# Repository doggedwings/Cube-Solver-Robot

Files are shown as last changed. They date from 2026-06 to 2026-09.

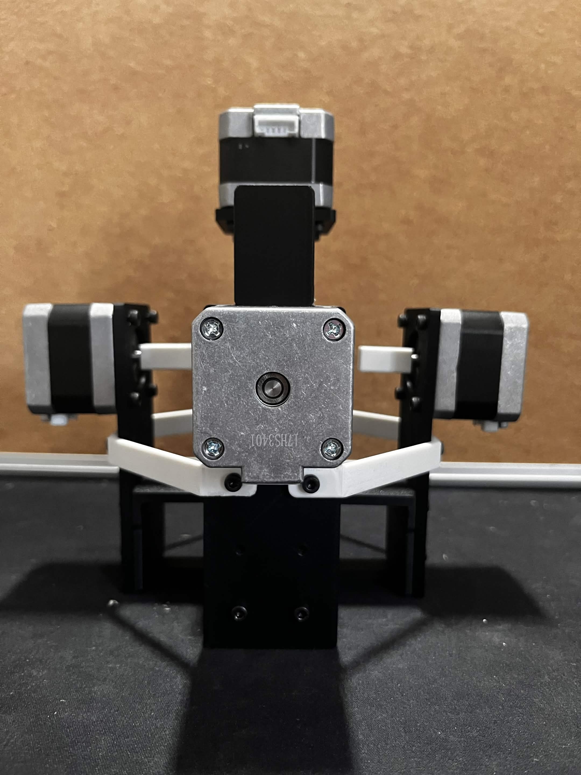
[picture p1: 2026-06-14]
Media/Side View.jpg

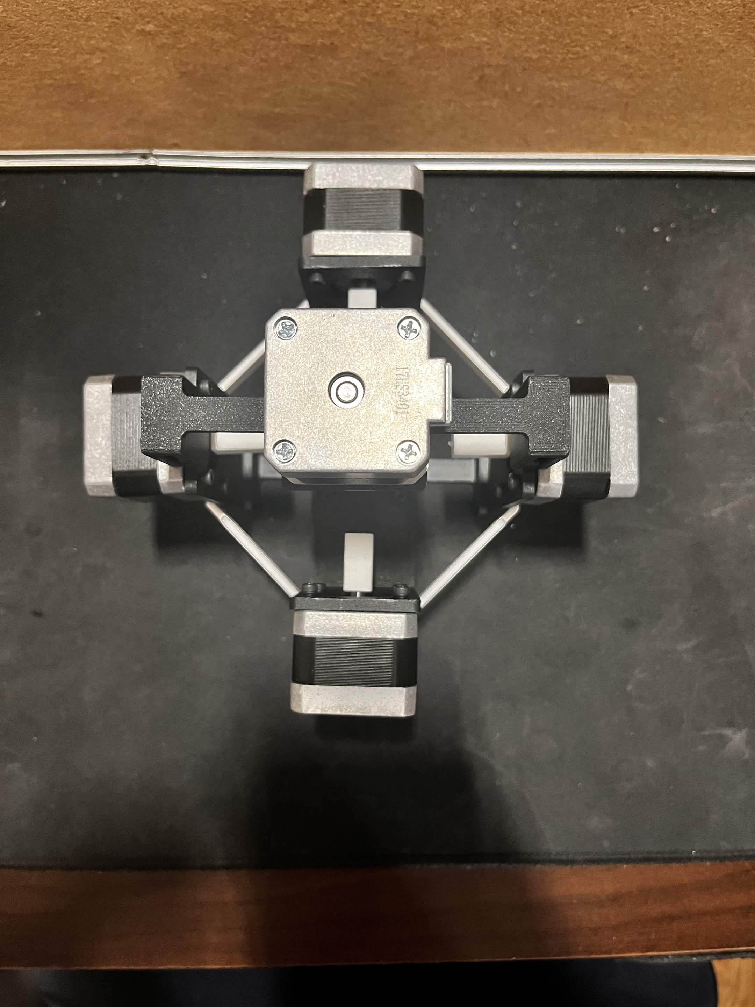
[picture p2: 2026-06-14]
Media/Top View.jpg

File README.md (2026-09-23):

# Rubik's Cube Solver Robot

An autonomous Rubik's Cube solving robot built around an ESP32, six NEMA 17 stepper motors, a custom 3D printed frame, and a web app that scans the cube using a phone camera and solves it with the Kociemba algorithm, which can solve a scrambled 3x3 cube in under 10 seconds. 



## WATCH THE SOLVE HERE 
https://youtube.com/shorts/RGmkUIyBiMk?feature=share

## Why I Built This
I've been solving Rubik's Cubes casually for almost a decade, and my best time is still over 20 seconds. I figured if I couldn't get faster, I'd build something that could. This robot scans a scrambled cube with a phone camera, computes the optimal solution, and physically solves it in well under 10 seconds using 6 stepper motors.

## How It Works

You scramble a cube and place it in the frame. Open the web app on your phone, calibrate the 6 colours, and scan all 6 faces by holding the cube up to the camera one face at a time. The app figures out the cube state, runs it through a solving algorithm, and sends the move sequence to the robot, which then physically executes every turn until the cube is solved.

## Hardware Specs

The Brain: ESP32-WROOM-32D, drives all 6 stepper motors over Serial commands
The Motors: 6x NEMA 17, one per cube face
The Drivers: 6x A4988 stepper drivers, full-step mode, ~50 steps per 90° turn
Power: 12V wall adapter for motors, USB for ESP32 logic
The Eyes: Phone camera or webcam for scanning cube faces
The Solver: Kociemba two-phase algorithm (Python), returns optimal solution in under a second
Frame & Couplers: Custom 3D printed (PETG), Fusion 360 designed

## Engineering 

1. Color Detection That Actually Works

Red and orange kept getting confused with fixed HSV thresholds. The fix was calibrating against the specific cube and lighting: white is detected by saturation (cutoff set between calibrated white and the least saturated colour), and every other sticker is classified by circular hue distance to the calibrated reference hues. This correctly handles red wrapping around 0/180 in HSV, which finally separated red from orange reliably. 

2. 6 Motor Coordination Over Serial

The ESP32 receives a full move sequence (e.g. R U2 D' B D' L2 F') as one string over Serial, parses it move by move, and executes each one including double turns and inverses by reversing direction or doubling the step count. Each motor also has its own tunable step count since print tolerances varied slightly across the 6 couplers. 

3. The Coupler Design (4 Iterations Deep)

Connecting a 5mm D shaft motor to a Rubik's cube center cap was harder than expected. The final design is a hex peg that seats into the center cap hole, with a D bore and set screw on the motor side. It took 4 print iterations since PETG shrinks about 0.1 to 0.2mm from the CAD dimensions, so each version had to compensate to get a snug fit. 

4. Phone Camera Over HTTPS

Browsers block camera access on non-HTTPS connections, so the Flask app runs with an ad hoc SSL context, letting the phone connect over the local network and stream camera frames to the server for processing. 

## Schematic 

*Note that the A4988 Motor Driver used in the schematic is different from the one used in the actual build, but the logic is the same, just the pinouts are different
Schematic

## CAD 

Custom design 3d printed frame made in Fusion 360, 6 motor mounts (4 side + top + bottom), magnetic top piece for easy clip on and off for cube loading, and stepper motor connector that goes into the stepper motor shaft and connects to a hex design cube connector that turns the face. 



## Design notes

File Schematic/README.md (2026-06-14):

## Note on A4988 Component

The A4988 symbol used in the KiCad schematic is not the exact same footprint as the physical Pololu A4988 breakout board used in the actual build. The correct breakout board footprint was not available in the KiCad library at the time. The pin functions and connections are identical, only the pin numbering differs between the schematic symbol and the physical board, so the wiring logic is fully accurate.

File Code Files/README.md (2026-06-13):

## Tutorial on how to run it

ESP32:

Open Motor_controller.ino in Arduino IDE
Board: ESP32 Dev Module, select the correct COM port, and upload

Web App:

IN TERMINAL OR BASH
pip install flask opencv-python numpy pyserial kociemba
python code/python/app.py

Open the printed HTTPS address on your phone, allow camera access, calibrate, scan, solve.

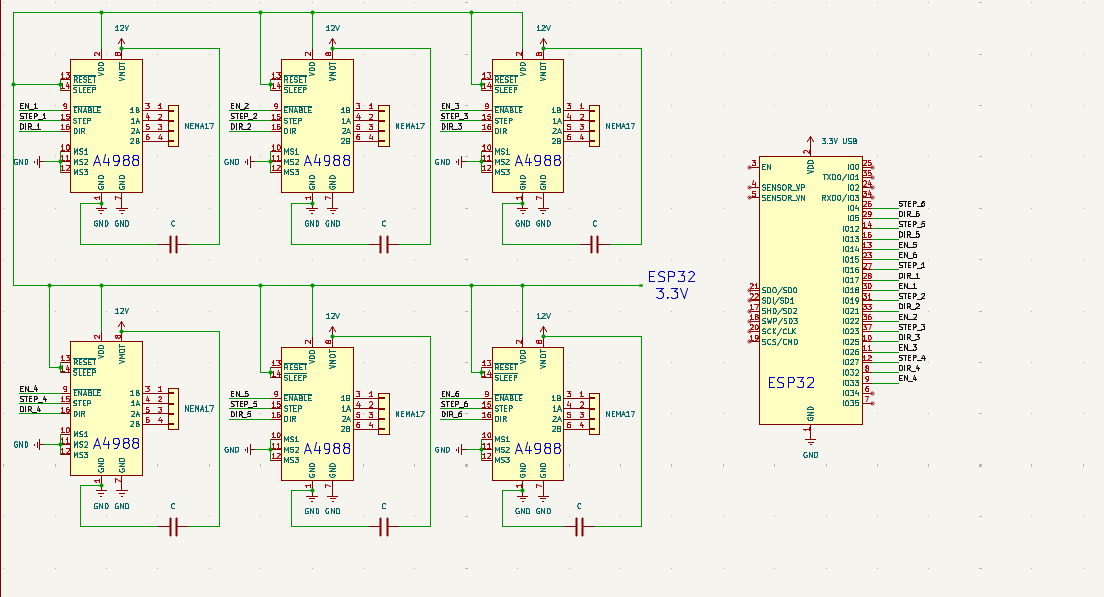
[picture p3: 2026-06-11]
Schematic/Schematic.png

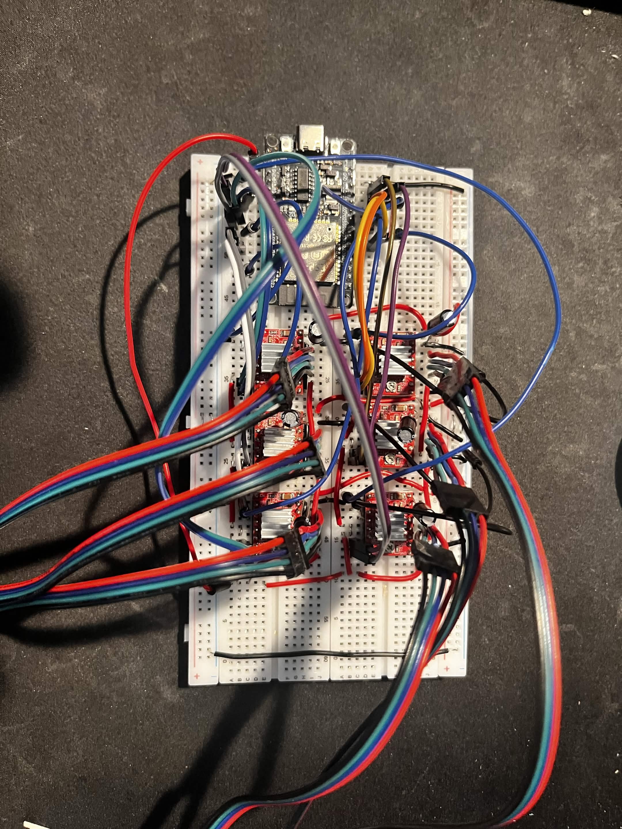
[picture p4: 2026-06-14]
Media/Built Breadboard Circuit.jpg

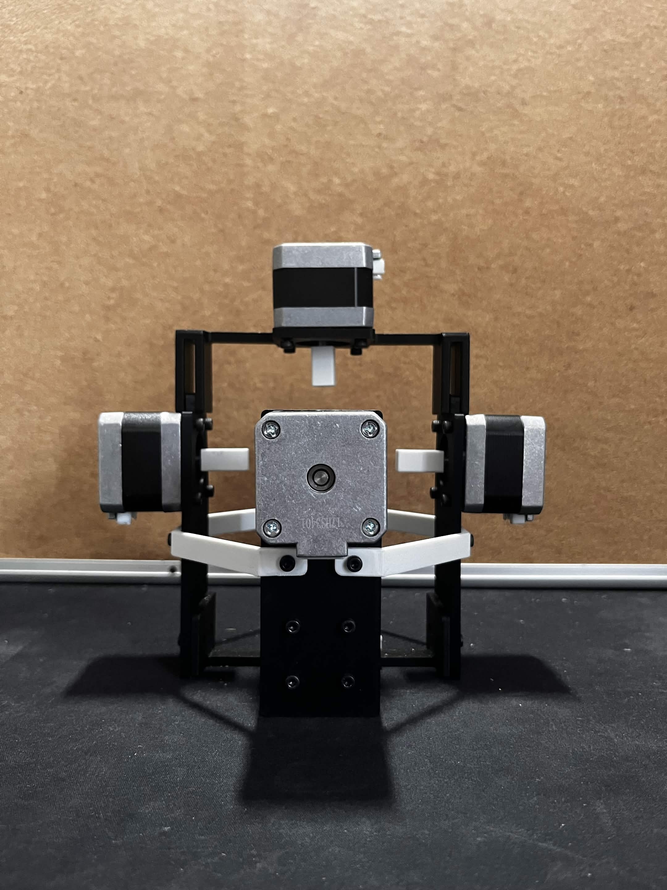
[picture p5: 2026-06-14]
Media/Front View.jpg

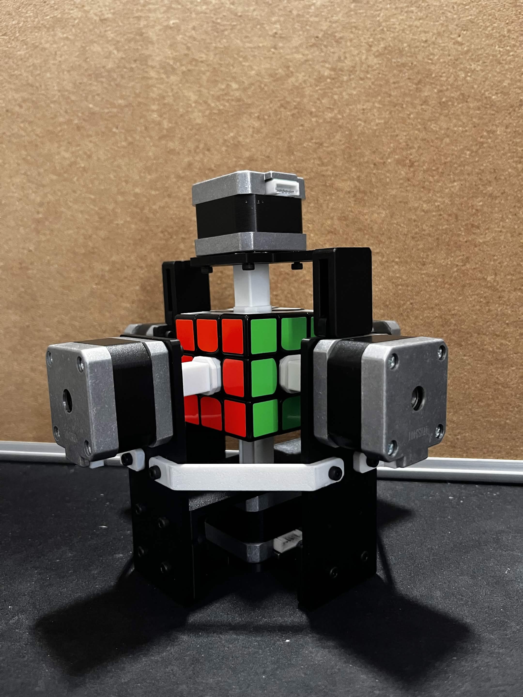
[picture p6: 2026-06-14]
Media/Full View.jpg

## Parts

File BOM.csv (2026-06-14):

Item | Amount | Source | Cost | Total Cost
ESP-32 | 1 | AliExpress | $4.50 | $4.50
A4988 | 6 | Amazon | $2.20 | $13.20
NEMA17 Pancake Stepper Motor | 6 | Amazon | $9.50 | $57.00
Rubicks Cube (GAN356, Moyu Weilong) | 1 | Already Have | $0.00 | $0.00

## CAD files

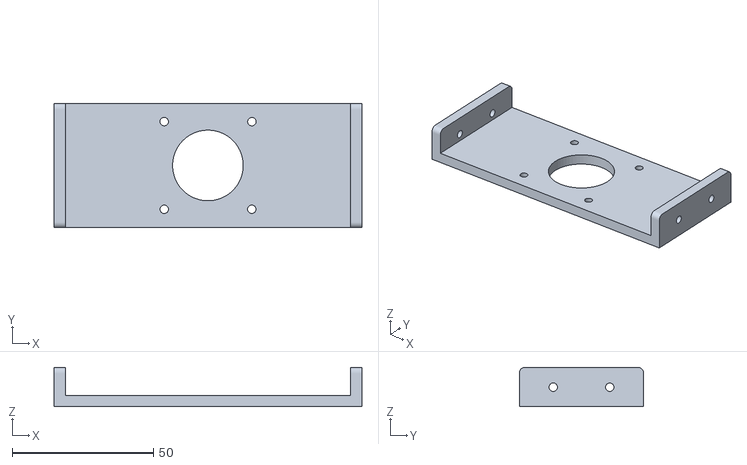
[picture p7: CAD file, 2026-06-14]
CAD Files/Base Plate.stl
109.0 x 44.0 x 14.0

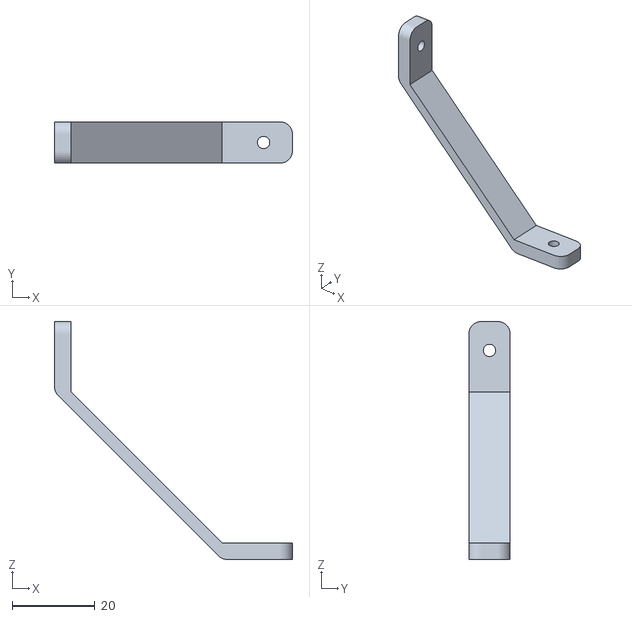
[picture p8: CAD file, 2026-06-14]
CAD Files/Side Plate Support Connector.stl
57.5 x 10.0 x 57.5

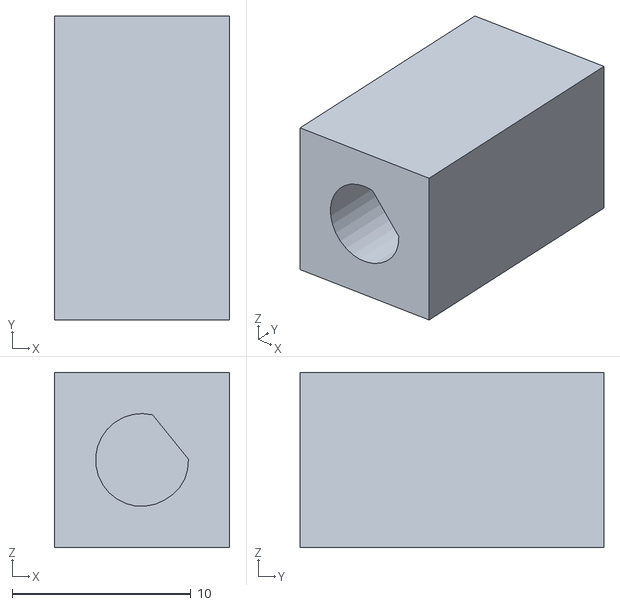
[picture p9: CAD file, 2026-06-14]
CAD Files/Stepper Motor Connector.stl
9.80 x 17.0 x 9.80

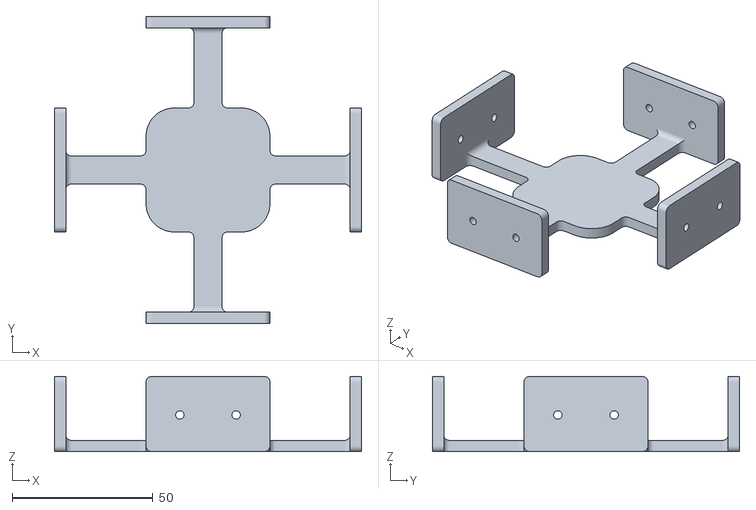
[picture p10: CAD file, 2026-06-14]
CAD Files/Base Web.stl
109.0 x 109.0 x 26.7

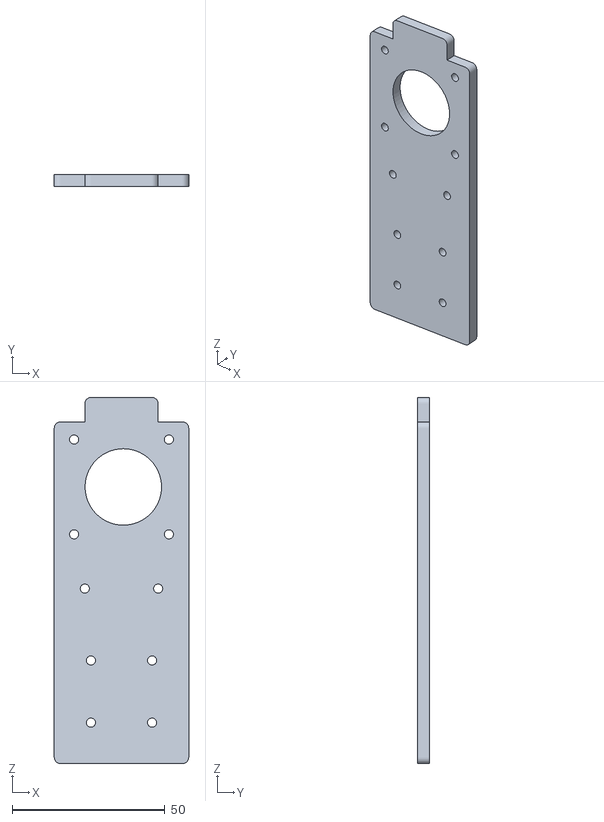
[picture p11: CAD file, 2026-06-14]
CAD Files/SIde Plate with Top Connector.stl
44.0 x 4.00 x 119.7

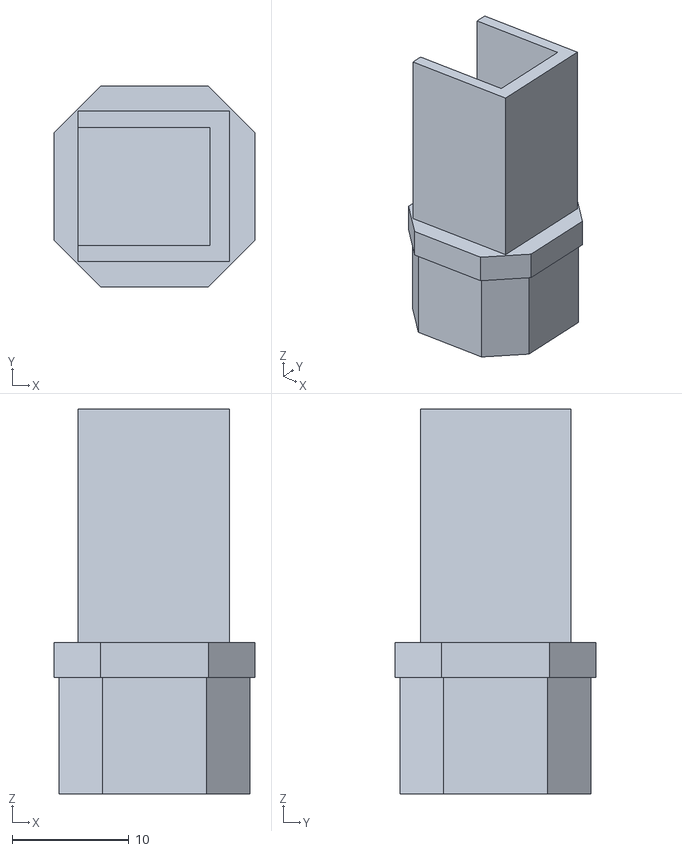
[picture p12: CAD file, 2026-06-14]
CAD Files/Cube Connector.stl
17.2 x 17.2 x 33.0

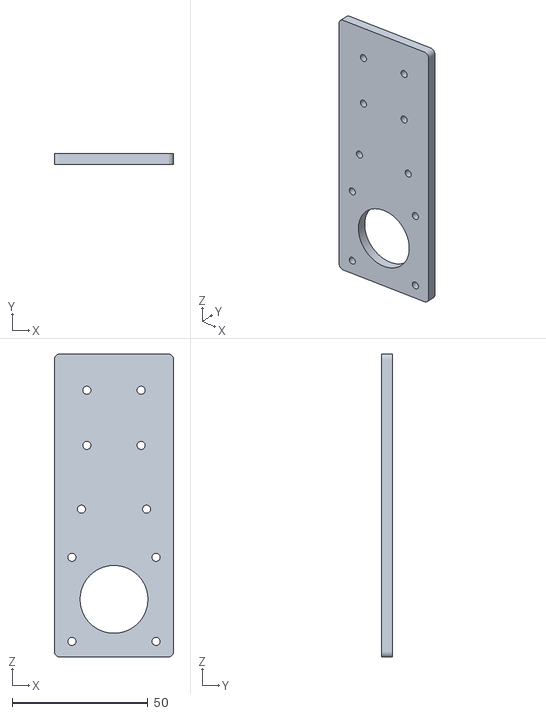
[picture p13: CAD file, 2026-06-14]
CAD Files/Side Plate no Top Connector.stl
44.0 x 4.00 x 111.7

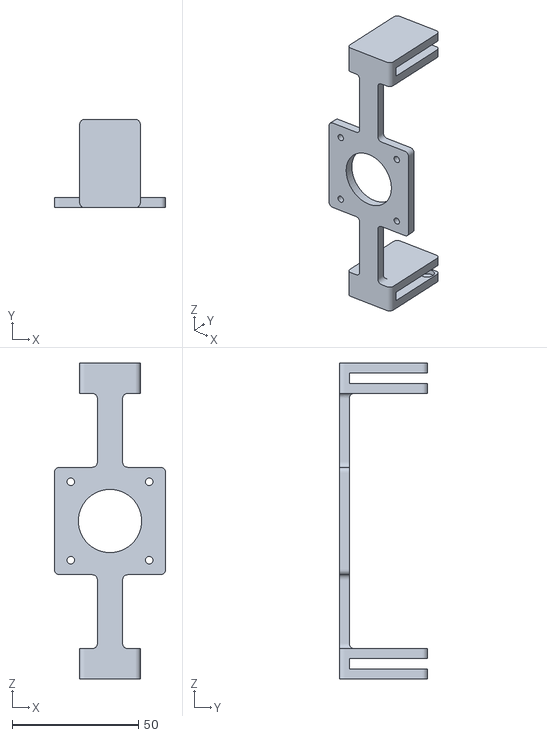
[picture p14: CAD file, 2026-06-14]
CAD Files/Top Connector.stl
44.0 x 35.0 x 125.0

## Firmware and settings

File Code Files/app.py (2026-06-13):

import cv2
import numpy as np
import kociemba
import threading
import time
import base64
import serial
import serial.tools.list_ports
from flask import Flask, Response, jsonify, render_template_string, request

app = Flask(__name__)

FACE_LABELS = {
    "U": "White / Up",
    "R": "Red / Right",
    "F": "Green / Front",
    "D": "Yellow / Down",
    "L": "Orange / Left",
    "B": "Blue / Back",
}

FACE_CSS = {
    "U": "#ffffff",
    "R": "#c41e3a",
    "F": "#009b48",
    "D": "#ffd500",
    "L": "#ff5800",
    "B": "#0046ad",
}

SERIAL_PORT = "COM3"
SERIAL_BAUD = 115200
serial_conn = None

def connect_serial():
    global serial_conn
    try:
        serial_conn = serial.Serial(SERIAL_PORT, SERIAL_BAUD, timeout=2)
        time.sleep(2)
        print(f"Serial connected on {SERIAL_PORT}")
    except Exception as e:
        print(f"Serial not connected: {e}")
        serial_conn = None

def send_solution_serial(solution_str):
    if serial_conn and serial_conn.is_open:
        serial_conn.write((solution_str + '\n').encode())
        print(f"Sent to ESP32: {solution_str}")
        return True
    print("Serial not connected")
    return False

state = {
    "refs": {},
    "faces": {f: None for f in "URFDLB"},
    "calibrating": True,
    "calib_face": "U",
    "solution": None,
    "error": None,
    "last_frame": None,  # base64 jpeg from phone
}
state_lock = threading.Lock()

# ── Colour helpers ────────────────────────────────────────────
def hue_dist(h1, h2):
    d = abs(int(h1) - int(h2))
    return min(d, 180 - d)

def color_dist(hsv1, ref):
    h1, s1, v1 = hsv1
    h2, s2, v2 = ref
    dh = hue_dist(h1, h2) * 2
    return dh * dh + (int(s1) - int(s2)) ** 2 + (int(v1) - int(v2)) ** 2

def build_thresholds(refs):
    """Adaptive thresholds anchored by the 6 calibration samples."""
    white_s = refs["U"][1]
    colored_sats = [refs[f][1] for f in "RFDLB"]
    min_colored_s = min(colored_sats)
    return {
        "white_s_max": (white_s + min_colored_s) / 2.0,
        "hues": {
            "R": refs["R"][0],
            "L": refs["L"][0],
            "D": refs["D"][0],
            "F": refs["F"][0],
            "B": refs["B"][0],
        },
    }

def classify_color(hsv, refs):
    """Calibrated hue-distance classifier.

    1. White detected by LOW SATURATION — cutoff sits halfway between the
       calibrated white saturation and the least-saturated colored face,
       so it adapts to your lighting instead of using a fixed number.
    2. All other stickers classified by NEAREST CALIBRATED HUE using
       circular hue distance — correctly handles red wrapping around
       0/180 in OpenCV HSV space, and separates red from orange based on
       the actual calibrated hues of YOUR cube under YOUR lighting.
    Value (brightness) is deliberately ignored for colors — brightness
    varies with shadows/angle but hue stays stable, which is what makes
    this approach accurate.
    """
    if len(refs) < 6:
        return "?"
    h, s, v = hsv
    t = build_thresholds(refs)
    if s <= t["white_s_max"] and v > 90:
        return "U"
    best, best_d = "U", 999
    for face, ref_h in t["hues"].items():
        d = hue_dist(h, ref_h)
        if d < best_d:
            best_d, best = d, face
    return best

def decode_frame(b64_data):
    """Decode base64 image from phone camera."""
    try:
        if ',' in b64_data:
            b64_data = b64_data.split(',')[1]
        img_bytes = base64.b64decode(b64_data)
        np_arr = np.frombuffer(img_bytes, np.uint8)
        frame = cv2.imdecode(np_arr, cv2.IMREAD_COLOR)
        return frame
    except Exception as e:
        print(f"Frame decode error: {e}")
        return None

def draw_calib_overlay(frame, face):
    fh, fw = frame.shape[:2]
    # Calibration box matches the size of ONE cell of the 3x3 scan grid
    side = int(min(fh, fw) * 0.85)
    grid_size = side // 3 - 6
    sz = grid_size // 2
    cx, cy = fw // 2, fh // 2
    x1, y1, x2, y2 = cx - sz, cy - sz, cx + sz, cy + sz
    cv2.rectangle(frame, (x1, y1), (x2, y2), (0, 255, 255), 3)
    cv2.putText(frame, f"Calibrate: {FACE_LABELS[face]}",
                (10, 30), cv2.FONT_HERSHEY_SIMPLEX, 0.65, (0, 255, 255), 2)
    hsv_f = cv2.cvtColor(frame, cv2.COLOR_BGR2HSV)
    roi = hsv_f[y1:y2, x1:x2]
    pad = max(1, sz // 2)
    if roi.shape[0] > 2 * pad and roi.shape[1] > 2 * pad:
        inner = roi[pad:-pad, pad:-pad]
    else:
        inner = roi
    ah = int(np.median(inner[:, :, 0]))
    as_ = int(np.median(inner[:, :, 1]))
    av = int(np.median(inner[:, :, 2]))
    cv2.putText(frame, f"HSV: {ah},{as_},{av}", (x1, y2 + 20),
                cv2.FONT_HERSHEY_SIMPLEX, 0.48, (255, 255, 0), 1)
    return (ah, as_, av)

def sample_face(frame, refs):
    h, w = frame.shape[:2]
    side = int(min(h, w) * 0.85)
    grid_size = side // 3 - 6
    spacing = 6
    total = 3 * grid_size + 2 * spacing
    sx = w // 2 - total // 2
    sy = h // 2 - total // 2
    hsv_frame = cv2.cvtColor(frame, cv2.COLOR_BGR2HSV)
    labels = []
    for row in range(3):
        for col in range(3):
            x = sx + col * (grid_size + spacing)
            y = sy + row * (grid_size + spacing)
            cv2.rectangle(frame, (x, y), (x + grid_size, y + grid_size), (0, 255, 0), 2)
            roi = hsv_frame[y:y + grid_size, x:x + grid_size]
            pad = grid_size // 4
            inner = roi[pad:-pad, pad:-pad]
            avg = (int(np.median(inner[:, :, 0])),
                   int(np.median(inner[:, :, 1])),
                   int(np.median(inner[:, :, 2])))
            label = classify_color(avg, refs) if refs else "?"
            labels.append(label)
            cv2.putText(frame, label, (x + 5, y + 22),
                        cv2.FONT_HERSHEY_SIMPLEX, 0.6, (0, 255, 0), 2)
    return labels

# ── Routes ────────────────────────────────────────────────────
@app.route("/")
def index():
    return render_template_string(HTML)

@app.route("/api/frame", methods=["POST"])
def api_frame():
    """Receive frame from phone camera via POST."""
    data = request.get_json()
    if not data or 'frame' not in data:
        return jsonify(error="No frame"), 400
    frame = decode_frame(data['frame'])
    if frame is None:
        return jsonify(error="Bad frame"), 400

    with state_lock:
        calibrating = state["calibrating"]
        calib_face = state["calib_face"]
        refs = dict(state["refs"])

    hsv_reading = None
    labels = None

    if calibrating and calib_face:
        hsv_reading = draw_calib_overlay(frame, calib_face)
        with state_lock:
            state["current_hsv"] = hsv_reading
    elif refs:
        labels = sample_face(frame, refs)

    ret, jpeg = cv2.imencode(".jpg", frame, [cv2.IMWRITE_JPEG_QUALITY, 72])
    if ret:
        b64 = base64.b64encode(jpeg.tobytes()).decode()
        with state_lock:
            state["last_frame"] = b64

    return jsonify(ok=True, hsv=hsv_reading, labels=labels)

@app.route("/api/state")
def api_state():
    with state_lock:
        refs_keys = list(state["refs"].keys())
        faces = {k: v for k, v in state["faces"].items()}
        calibrating = state["calibrating"]
        calib_face = state["calib_face"]
        solution = state["solution"]
        error = state["error"]
        last_frame = state.get("last_frame")
    serial_status = "connected" if serial_conn and serial_conn.is_open else "disconnected"
    return jsonify(refs=refs_keys, faces=faces, calibrating=calibrating,
                   calib_face=calib_face, solution=solution, error=error,
                   serial=serial_status, last_frame=last_frame)

@app.route("/api/calibrate/<face>", methods=["POST"])
def api_calibrate(face):
    face = face.upper()
    if face not in "URFDLB":
        return jsonify(error="Invalid face"), 400
    with state_lock:
        hsv = state.get("current_hsv")
        if hsv is None:
            return jsonify(error="No frame yet — point camera at cube first"), 500
        state["refs"][face] = hsv
        order = list("URFDLB")
        idx = order.index(face)
        if idx + 1 < len(order):
            state["calib_face"] = order[idx + 1]
            state["calibrating"] = True
        else:
            state["calibrating"] = False
            state["calib_face"] = None
    return jsonify(ok=True, face=face, hsv=hsv)

@app.route("/api/capture/<face>", methods=["POST"])
def api_capture(face):
    face = face.upper()
    if face not in "URFDLB":
        return jsonify(error="Invalid face"), 400
    with state_lock:
        refs = dict(state["refs"])
        last_frame_b64 = state.get("last_frame")
    if len(refs) < 6:
        return jsonify(error="Calibrate all 6 faces first"), 400
    if last_frame_b64 is None:
        return jsonify(error="No frame available"), 500
    img_bytes = base64.b64decode(last_frame_b64)
    np_arr = np.frombuffer(img_bytes, np.uint8)
    raw = cv2.imdecode(np_arr, cv2.IMREAD_COLOR)
    labels = sample_face(raw, refs)
    labels[4] = face
    with state_lock:
        state["faces"][face] = labels
    return jsonify(face=face, labels=labels)

@app.route("/api/solve", methods=["POST"])
def api_solve():
    with state_lock:
        faces = {k: v for k, v in state["faces"].items()}
    if any(v is None for v in faces.values()):
        return jsonify(error="Not all 6 faces captured yet"), 400
    cube_str = "".join("".join(faces[f]) for f in "URFDLB")
    try:
        solution = kociemba.solve(cube_str)
        serial_sent = send_solution_serial(solution)
        with state_lock:
            state["solution"] = solution
            state["error"] = None
        return jsonify(solution=solution, cube_str=cube_str, serial_sent=serial_sent)
    except Exception as exc:
        with state_lock:
            state["solution"] = None
            state["error"] = str(exc)
        return jsonify(error=str(exc)), 400

@app.route("/api/set_cell/<face>/<int:index>/<color>", methods=["POST"])
def api_set_cell(face, index, color):
    face = face.upper()
    color = color.upper()
    if face not in "URFDLB" or color not in "URFDLB":
        return jsonify(error="Invalid"), 400
    if not (0 <= index <= 8):
        return jsonify(error="Invalid index"), 400
    with state_lock:
        if state["faces"][face] is None:
            state["faces"][face] = [face] * 9
        state["faces"][face][index] = color
    return jsonify(ok=True)

@app.route("/api/reset", methods=["POST"])
def api_reset():
    with state_lock:
        state["refs"] = {}
        state["faces"] = {f: None for f in "URFDLB"}
        state["calibrating"] = True
        state["calib_face"] = "U"
        state["solution"] = None
        state["error"] = None
        state["last_frame"] = None
        state["current_hsv"] = None
    return jsonify(ok=True)

@app.route("/api/serial_ports")
def api_serial_ports():
    ports = [p.device for p in serial.tools.list_ports.comports()]
    return jsonify(ports=ports)

@app.route("/api/connect_serial/<port>", methods=["POST"])
def api_connect_serial(port):
    global serial_conn, SERIAL_PORT
    SERIAL_PORT = port
    connect_serial()
    connected = serial_conn and serial_conn.is_open
    return jsonify(ok=connected, port=port)

HTML = r"""<!DOCTYPE html>
<html lang="en">
<head>
<meta charset="UTF-8">
<meta name="viewport" content="width=device-width, initial-scale=1.0, maximum-scale=1.0">
<title>Cube Solver</title>
<style>
*, *::before, *::after { box-sizing: border-box; margin: 0; padding: 0; }
body {
  background: #14142b;
  color: #e0e0e0;
  font-family: 'Segoe UI', system-ui, sans-serif;
  min-height: 100vh;
  padding-bottom: 40px;
}
h1 {
  text-align: center;
  padding: 16px 0 8px;
  font-size: 1.4rem;
  color: #f0c040;
  letter-spacing: 2px;
}
.container { max-width: 520px; margin: 0 auto; padding: 0 16px; }

/* Camera */
#camera-wrap {
  position: relative;
  width: 100%;
  background: #000;
  border-radius: 10px;
  overflow: hidden;
  margin-bottom: 12px;
}
#phone-camera {
  width: 100%;
  display: block;
  border-radius: 10px;
}
#overlay-canvas {
  position: absolute;
  top: 0; left: 0;
  width: 100%; height: 100%;
  pointer-events: none;
}
#preview-img {
  width: 100%;
  display: none;
  border-radius: 10px;
}

.banner {
  background: #1c1c3a;
  border: 1px solid #333;
  border-radius: 8px;
  padding: 8px 12px;
  font-size: 0.88rem;
  margin-bottom: 10px;
}
.banner span { color: #f0c040; font-weight: bold; }

.serial-row {
  display: flex;
  align-items: center;
  gap: 8px;
  background: #1c1c3a;
  border: 1px solid #333;
  border-radius: 8px;
  padding: 8px 12px;
  margin-bottom: 10px;
  font-size: 0.82rem;
}
.dot { width: 9px; height: 9px; border-radius: 50%; background: #f44336; flex-shrink: 0; }
.dot.on { background: #4caf50; }
select {
  background: #2a2a4a; color: #eee;
  border: 1px solid #444; border-radius: 4px;
  padding: 3px 6px; flex: 1; font-size: 0.8rem;
}

.section-lbl {
  font-size: 0.7rem; color: #888;
  text-transform: uppercase; letter-spacing: 1px;
  margin-bottom: 6px;
}
.btn-row { display: flex; flex-wrap: wrap; gap: 7px; margin-bottom: 10px; }
button {
  padding: 8px 12px; border-radius: 6px; border: none;
  cursor: pointer; font-weight: 600; font-size: 0.8rem;
  transition: opacity .15s, transform .1s;
}
button:active { transform: scale(0.97); }
button:disabled { opacity: .35; cursor: not-allowed; }
.btn-calib   { background: #00b4d8; color: #000; }
.btn-calib.done { background: #2e7d32; color: #c8e6c9; }
.btn-capture { background: #388e3c; color: #fff; }
.btn-capture.done { background: #1b5e20; }
.btn-solve   { background: #f0c040; color: #000; font-size: .9rem; padding: 10px 20px; }
.btn-reset   { background: #424242; color: #eee; }
.btn-serial  { background: #7c4dff; color: #fff; font-size: 0.78rem; padding: 5px 10px; }

.result-box {
  border-radius: 8px; padding: 12px 14px; font-size: .88rem; margin-top: 10px;
}
.result-box.ok  { background: #0d3b1f; border: 1px solid #2e7d32; }
.result-box.err { background: #3b0d0d; border: 1px solid #b71c1c; color: #ff8a80; }
.result-box h3  { margin-bottom: 6px; color: #f0c040; }
.moves { font-family: monospace; font-size: 1rem; letter-spacing: 2px; word-break: break-all; }

/* Cube net */
.cube-net {
  display: grid;
  grid-template-columns: repeat(4, auto);
  grid-template-areas:
    ".  U  .  ."
    "L  F  R  B"
    ".  D  .  .";
  gap: 5px;
  justify-content: center;
  margin-bottom: 14px;
}
[data-area="U"] { grid-area: U; }
[data-area="L"] { grid-area: L; }
[data-area="F"] { grid-area: F; }
[data-area="R"] { grid-area: R; }
[data-area="B"] { grid-area: B; }
[data-area="D"] { grid-area: D; }
.face-wrap { display: flex; flex-direction: column; align-items: center; gap: 3px; }
.face-lbl { font-size: .62rem; color: #888; }
.face-grid {
  display: grid;
  grid-template-columns: repeat(3, 28px);
  grid-template-rows: repeat(3, 28px);
  gap: 2px; border-radius: 3px; padding: 2px;
}
.face-grid.captured { outline: 2px solid #4caf50; }
.face-grid.active   { outline: 2px solid #00b4d8; }
.cell {
  width: 28px; height: 28px; border-radius: 3px;
  background: #2a2a4a; border: 1px solid #1a1a2e;
  cursor: pointer;
}
</style>
</head>
<body>
<h1>🟧 Cube Solver</h1>
<div class="container">

  <!-- Camera -->
  <div id="camera-wrap">
    <video id="phone-camera" autoplay playsinline muted></video>
    <img id="overlay-img" style="position:absolute;top:0;left:0;width:100%;height:100%;border-radius:10px;pointer-events:none;display:none;">
  </div>

  <!-- Phase -->
  <div class="banner">Phase: <span id="phase-text">Calibration</span></div>

  <!-- Serial -->
  <div class="serial-row">
    <div class="dot" id="serial-dot"></div>
    <span id="serial-status">Serial: disconnected</span>
    <select id="port-select"></select>
    <button class="btn-serial" onclick="connectSerial()">Connect</button>
  </div>

  <!-- Cube net -->
  <div class="section-lbl">Cube faces</div>
  <div class="cube-net">
    <div class="face-wrap" data-area="U"><div class="face-lbl">U·White</div><div class="face-grid" id="face-U"></div></div>
    <div class="face-wrap" data-area="L"><div class="face-lbl">L·Orange</div><div class="face-grid" id="face-L"></div></div>
    <div class="face-wrap" data-area="F"><div class="face-lbl">F·Green</div><div class="face-grid" id="face-F"></div></div>
    <div class="face-wrap" data-area="R"><div class="face-lbl">R·Red</div><div class="face-grid" id="face-R"></div></div>
    <div class="face-wrap" data-area="B"><div class="face-lbl">B·Blue</div><div class="face-grid" id="face-B"></div></div>
    <div class="face-wrap" data-area="D"><div class="face-lbl">D·Yellow</div><div class="face-grid" id="face-D"></div></div>
  </div>

  <!-- Calibration -->
  <div class="section-lbl">1 · Calibrate — point center sticker at box, tap button</div>
  <div class="btn-row">
    <button class="btn-calib" id="calib-U" onclick="calibrate('U')">U·White</button>
    <button class="btn-calib" id="calib-R" onclick="calibrate('R')">R·Red</button>
    <button class="btn-calib" id="calib-F" onclick="calibrate('F')">F·Green</button>
    <button class="btn-calib" id="calib-D" onclick="calibrate('D')">D·Yellow</button>
    <button class="btn-calib" id="calib-L" onclick="calibrate('L')">L·Orange</button>
    <button class="btn-calib" id="calib-B" onclick="calibrate('B')">B·Blue</button>
  </div>

  <!-- Capture -->
  <div class="section-lbl">2 · Capture each face</div>
  <div class="btn-row">
    <button class="btn-capture" id="cap-U" onclick="capture('U')">U↑</button>
    <button class="btn-capture" id="cap-R" onclick="capture('R')">R→</button>
    <button class="btn-capture" id="cap-F" onclick="capture('F')">F●</button>
    <button class="btn-capture" id="cap-D" onclick="capture('D')">D↓</button>
    <button class="btn-capture" id="cap-L" onclick="capture('L')">L←</button>
    <button class="btn-capture" id="cap-B" onclick="capture('B')">B●</button>
  </div>

  <div class="btn-row">
    <button class="btn-solve" onclick="solve()">🔍 Solve & Send</button>
    <button class="btn-reset" onclick="resetAll()">↺ Reset</button>
  </div>

  <div id="result-area"></div>
</div>

<script>
const FACE_CSS = { U:'#ffffff', R:'#c41e3a', F:'#009b48', D:'#ffd500', L:'#ff5800', B:'#0046ad' };
const COLOR_ORDER = ['U','R','F','D','L','B'];
const faceLabels = {};
let streaming = false;
let sendInterval = null;

// Build face grids
['U','R','F','D','L','B'].forEach(f => {
  const g = document.getElementById('face-' + f);
  faceLabels[f] = null;
  let html = '';
  for (let i = 0; i < 9; i++) html += `<div class="cell" data-face="${f}" data-idx="${i}"></div>`;
  g.innerHTML = html;
  g.querySelectorAll('.cell').forEach(cell => cell.addEventListener('click', () => cycleCell(cell)));
});

// Start phone camera
async function startCamera() {
  try {
    const stream = await navigator.mediaDevices.getUserMedia({
      video: { facingMode: 'environment', width: { ideal: 640 }, height: { ideal: 480 } }
    });
    const video = document.getElementById('phone-camera');
    video.srcObject = stream;
    streaming = true;
    sendInterval = setInterval(sendFrame, 200); // send frame every 200ms
  } catch(e) {
    alert('Camera access denied — please allow camera permission and refresh');
  }
}

// Send frame to server
async function sendFrame() {
  if (!streaming) return;
  const video = document.getElementById('phone-camera');
  if (video.readyState < 2) return;
  const canvas = document.createElement('canvas');
  canvas.width = video.videoWidth;
  canvas.height = video.videoHeight;
  const ctx = canvas.getContext('2d');
  ctx.drawImage(video, 0, 0);
  const b64 = canvas.toDataURL('image/jpeg', 0.7);
  try {
    await fetch('/api/frame', {
      method: 'POST',
      headers: { 'Content-Type': 'application/json' },
      body: JSON.stringify({ frame: b64 })
    });
  } catch(_) {}
}

function cycleCell(cell) {
  const face = cell.dataset.face;
  const idx = parseInt(cell.dataset.idx);
  if (!faceLabels[face]) return;
  const cur = faceLabels[face][idx];
  const next = COLOR_ORDER[(COLOR_ORDER.indexOf(cur) + 1) % COLOR_ORDER.length];
  faceLabels[face][idx] = next;
  cell.style.background = FACE_CSS[next] || '#333';
  fetch(`/api/set_cell/${face}/${idx}/${next}`, { method: 'POST' });
}

function renderFace(face, labels) {
  faceLabels[face] = [...labels];
  const g = document.getElementById('face-' + face);
  const cells = g.querySelectorAll('.cell');
  labels.forEach((lbl, i) => { cells[i].style.background = FACE_CSS[lbl] || '#333'; cells[i].title = lbl; });
  g.classList.add('captured');
  g.classList.remove('active');
}

function clearFace(face) {
  faceLabels[face] = null;
  const g = document.getElementById('face-' + face);
  g.querySelectorAll('.cell').forEach(c => { c.style.background = ''; c.title = ''; });
  g.classList.remove('captured', 'active');
}

async function calibrate(face) {
  const res = await fetch('/api/calibrate/' + face, { method: 'POST' });
  const data = await res.json();
  if (data.ok) {
    const btn = document.getElementById('calib-' + face);
    btn.classList.add('done');
    if (!btn.textContent.includes('✓')) btn.textContent += ' ✓';
  } else {
    showResult(data.error, 'err');
  }
  await pollState();
}

async function capture(face) {
  const res = await fetch('/api/capture/' + face, { method: 'POST' });
  const data = await res.json();
  if (data.labels) {
    renderFace(face, data.labels);
    document.getElementById('cap-' + face).classList.add('done');
  } else {
    showResult(data.error || 'Capture failed', 'err');
  }
}
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

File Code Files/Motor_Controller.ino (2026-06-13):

// Motor 1 - Bottom - Down
#define D_STEP 16
#define D_DIR  17
#define D_EN   18

// Motor 2 - Side - Front
#define F_STEP 19
#define F_DIR  21
#define F_EN   22

// Motor 3 - Side - Left
#define L_STEP 23
#define L_DIR  25
#define L_EN   26

// Motor 4 - Side - Right
#define R_STEP 12
#define R_DIR  13
#define R_EN   14

// Motor 5 - Side - Back
#define B_STEP 27
#define B_DIR  32
#define B_EN   33

// Motor 6 - Top - Up
#define U_STEP 4
#define U_DIR  5
#define U_EN   15

#define STEP_DELAY_US  800
#define MOVE_PAUSE_MS  300

int stepsPerFace[] = {53, 50, 50, 50, 50, 50}; // D, F, L, R, B, U

int stepPins[] = {D_STEP, F_STEP, L_STEP, R_STEP, B_STEP, U_STEP};
int dirPins[]  = {D_DIR,  F_DIR,  L_DIR,  R_DIR,  B_DIR,  U_DIR};
int enPins[]   = {D_EN,   F_EN,   L_EN,   R_EN,   B_EN,   U_EN};

void setup() {
  delay(2000);
  Serial.begin(115200);
  for (int i = 0; i < 6; i++) {
    pinMode(stepPins[i], OUTPUT);
    pinMode(dirPins[i],  OUTPUT);
    pinMode(enPins[i],   OUTPUT);
    digitalWrite(enPins[i],   LOW);
    digitalWrite(dirPins[i],  HIGH);
    digitalWrite(stepPins[i], LOW);
  }
  Serial.println("Ready — waiting for solve command...");
}

void rotateFace(int faceIndex, int dirPin, bool clockwise) {
  digitalWrite(dirPin, clockwise ? HIGH : LOW);
  delayMicroseconds(5);
  int steps = stepsPerFace[faceIndex];
  int stepPin = stepPins[faceIndex];
  for (int i = 0; i < steps; i++) {
    digitalWrite(stepPin, HIGH);
    delayMicroseconds(STEP_DELAY_US);
    digitalWrite(stepPin, LOW);
    delayMicroseconds(STEP_DELAY_US);
  }
}

void moveU(bool cw = true) { rotateFace(5, U_DIR, !cw); }
void moveD(bool cw = true) { rotateFace(0, D_DIR, !cw); }
void moveF(bool cw = true) { rotateFace(1, F_DIR, !cw); }
void moveB(bool cw = true) { rotateFace(4, B_DIR, !cw); }
void moveL(bool cw = true) { rotateFace(2, L_DIR, !cw); }
void moveR(bool cw = true) { rotateFace(3, R_DIR, !cw); }

void moveU2() { moveU(); moveU(); }
void moveD2() { moveD(); moveD(); }
void moveF2() { moveF(); moveF(); }
void moveB2() { moveB(); moveB(); }
void moveL2() { moveL(); moveL(); }
void moveR2() { moveR(); moveR(); }

void executeMove(String move) {
  move.trim();
  Serial.println(move);
  if      (move == "U")  moveU();
  else if (move == "U'") moveU(false);
  else if (move == "U2") moveU2();
  else if (move == "D")  moveD();
  else if (move == "D'") moveD(false);
  else if (move == "D2") moveD2();
  else if (move == "F")  moveF();
  else if (move == "F'") moveF(false);
  else if (move == "F2") moveF2();
  else if (move == "B")  moveB();
  else if (move == "B'") moveB(false);
  else if (move == "B2") moveB2();
  else if (move == "L")  moveL();
  else if (move == "L'") moveL(false);
  else if (move == "L2") moveL2();
  else if (move == "R")  moveR();
  else if (move == "R'") moveR(false);
  else if (move == "R2") moveR2();
  else Serial.println("Unknown move: " + move);
}

void loop() {
  if (Serial.available()) {
    String line = Serial.readStringUntil('\n');
    line.trim();
    if (line.length() == 0) return;
    Serial.println("Received: " + line);
    Serial.println("--- Solving ---");
    int start = 0;
    while (start < (int)line.length()) {
      int sp = line.indexOf(' ', start);
      String move;
      if (sp == -1) {
        move = line.substring(start);
        start = line.length();
      } else {
        move = line.substring(start, sp);
        start = sp + 1;
      }
      if (move.length() > 0) {
        executeMove(move);
        delay(MOVE_PAUSE_MS);
      }
    }
    Serial.println("=== Solve Complete! ===");
  }
}

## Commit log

2026-06-14 Create CAD Files
2026-06-14 Update and rename BOM - Sheet1.csv to BOM.csv
    [BOM.csv]
